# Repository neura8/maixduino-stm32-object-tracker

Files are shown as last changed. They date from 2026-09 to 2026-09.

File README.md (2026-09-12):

# maixduino-stm32-object-tracker
Embedded real-time object tracking with Maixduino, STM32 NUCLEO-F446RE, UART, and PWM servo control.

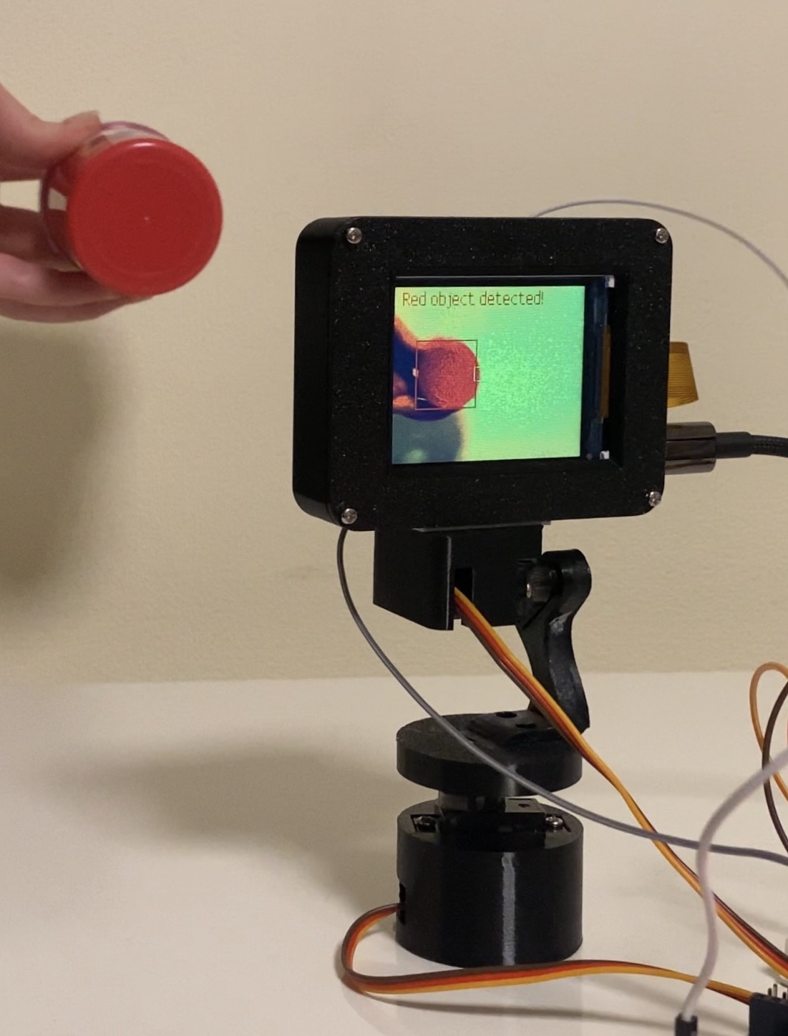
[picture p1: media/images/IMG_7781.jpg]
Main photo


The system detects a red object using an OV2640 camera, calculates its position relative to the center of the frame, and automatically rotates the camera using two MG90S servo motors.

## Features

- Red object detection
- Real-time pan-tilt tracking
- UART communication between Maixduino and STM32
- PWM control of two MG90S servo motors
- Dead zone for stable positioning
- Maximum ±90° movement from the base position
- Smooth return to the base position
- LCD visualization with object bounding box

## Hardware

[Components List](components-list.md)

### Connection Diagram

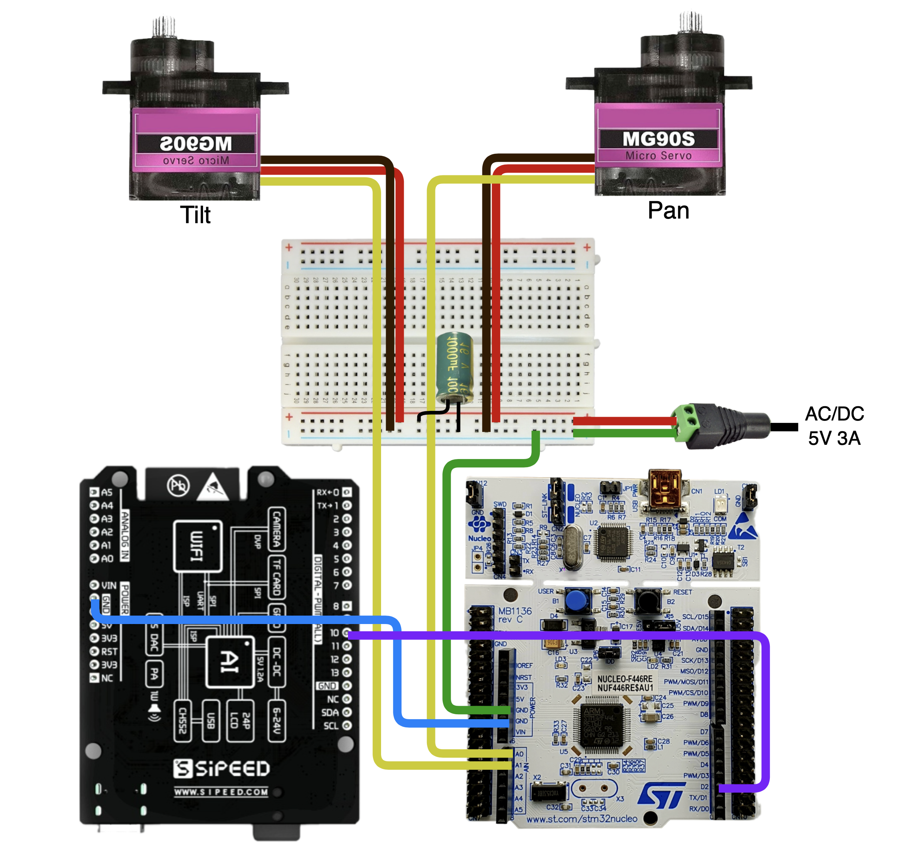
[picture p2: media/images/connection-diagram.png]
Connection Diagram


## Firmware

To program the boards, I used MaixPy IDE for the Maixduino and STM32CubeIDE for the NUCLEO-F446RE.

### Maixduino handles:
- Camera input
- Red object detection
- Object center calculation
- Pan and tilt angle calculation
- UART transmission

[MaixPy Source Code](maixduino/main.py)

### STM32 NUCLEO-F446RE handles:
- UART reception
- Angle parsing
- PWM generation
- Pan and tilt servo control

[STM32 Source Code](stm32-nucleo/main.c)

## Servo Control

- Pan servo: PA0 / TIM2_CH1
- Tilt servo: PA1 / TIM2_CH2
- PWM frequency: 50 Hz
- PWM period: 20 ms
- Servo angle range: 0–180°
- Base position: 90°
- Maximum offset: ±90°

## System Architecture

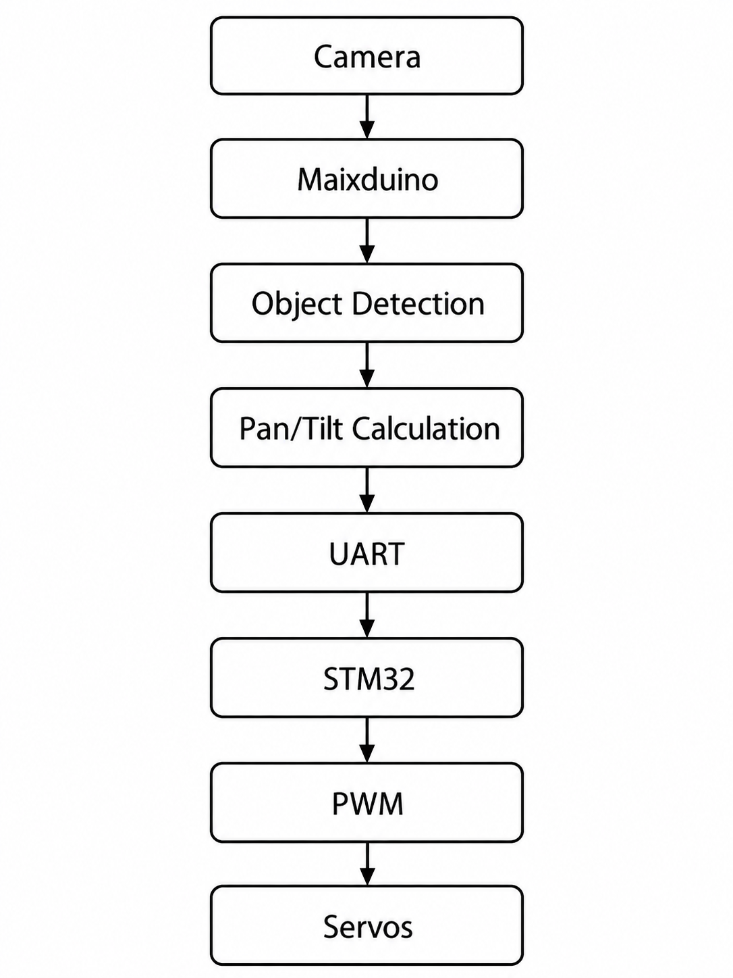
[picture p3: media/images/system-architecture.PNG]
System Architecture


## 3D Parts

I also designed my own 3D pan-tilt mechanism in Fusion 360. Here are the STL files:

[3D Printable Parts](cad/3D-prints/)

## Documentation

[Project Presentation (PDF)](docs/proj-presentation.pdf)

## Result

[Video demo](media/video/result.mov)

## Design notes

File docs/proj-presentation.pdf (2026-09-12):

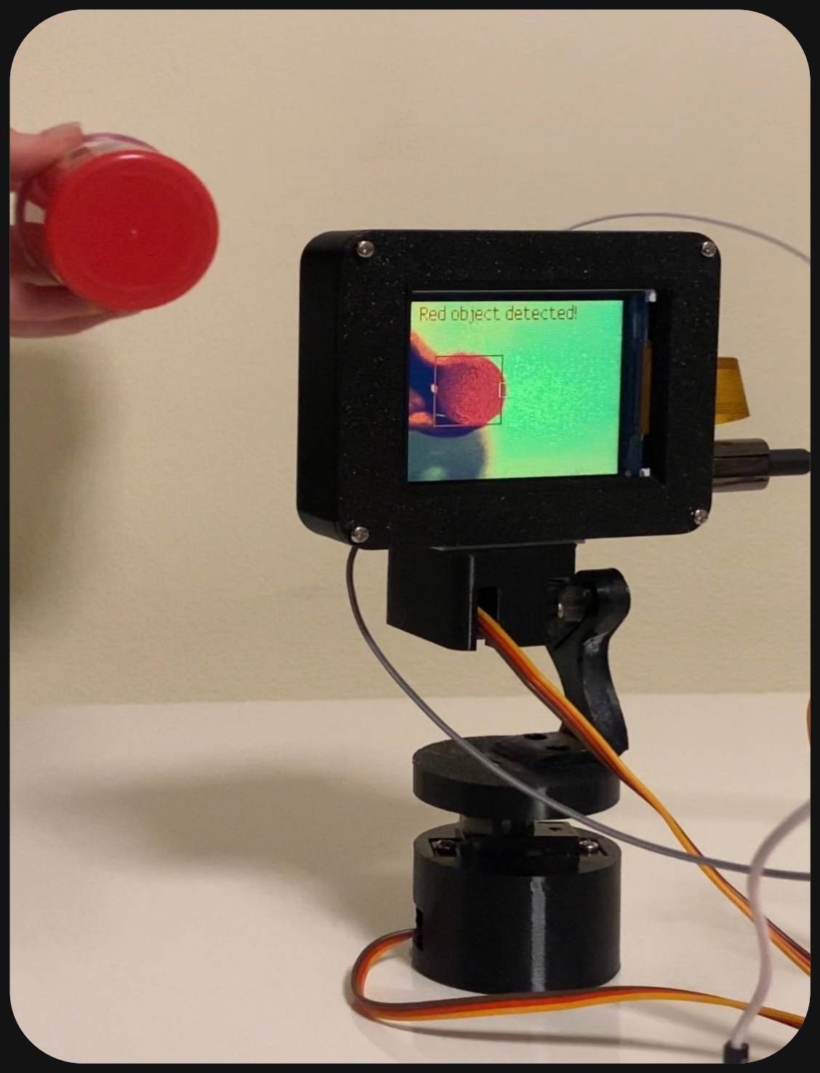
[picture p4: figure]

# Edge Vision Pan-Tilt Tracker

real-time object tracking system using Maixduino, camera module, STM32 NUCLEO-F446RE, UART communication, and PWM servo control

# Idea

Building a tracker that recognizes a red object in the frame and automatically rotates the camera to follow it along two axes.

Component | Quantity

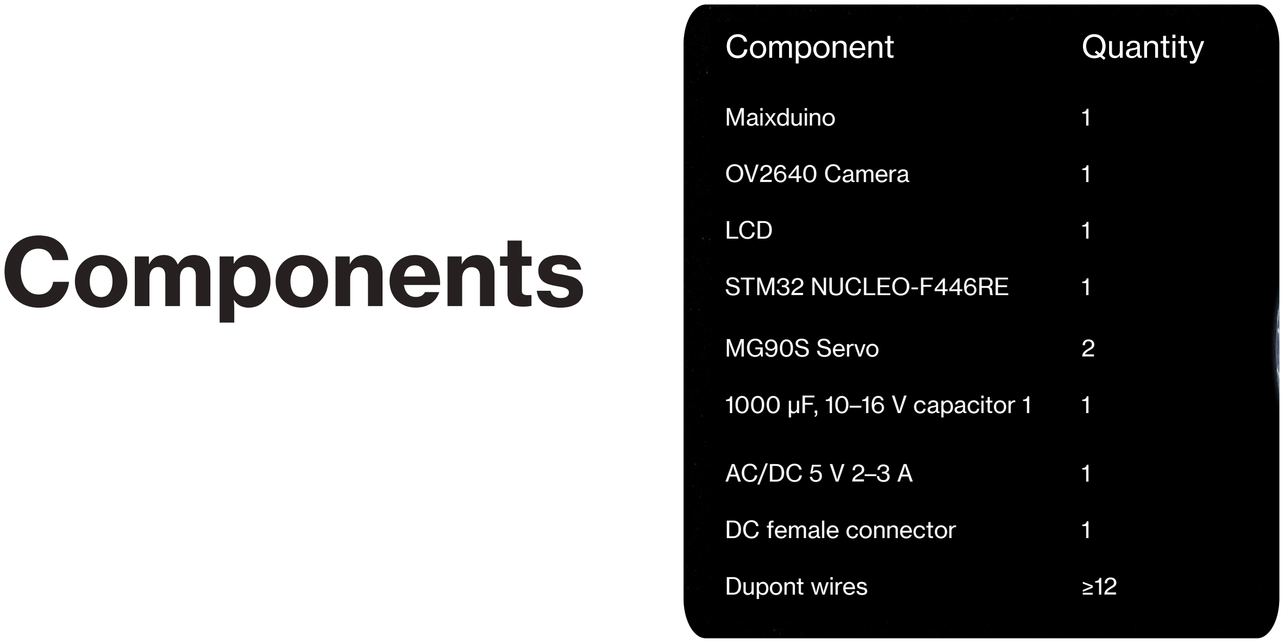
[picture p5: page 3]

# Components

Maixduino | 1
OV2640 Camera | 1
LCD | 1
STM32 NUCLEO-F446RE | 1
MG90S Servo | 2
1000 µF, 10–16 V capacitor 1 | 1
AC/DC 5 V 2–3 A | 1
DC female connector | 1
Dupont wires | ≥12

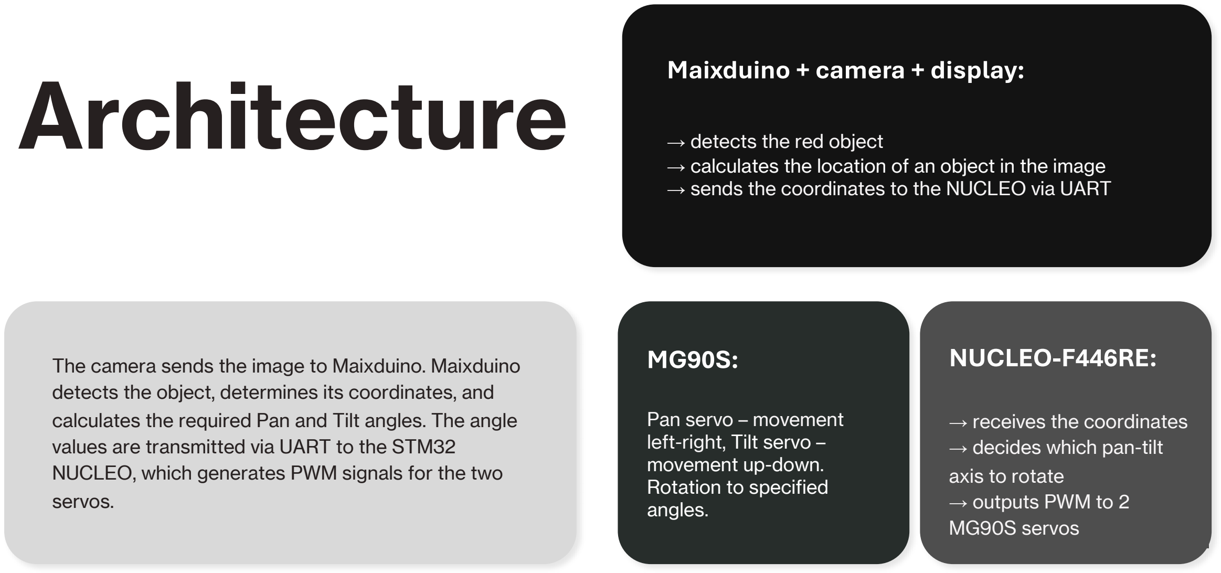
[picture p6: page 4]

Architecture → detects the red object

→ calculates the location of an object in the image → sends the coordinates to the NUCLEO via UART

Maixduino + camera + display:

The camera sends the image to Maixduino. Maixduino detects the object, determines its coordinates, and calculates the required Pan and Tilt angles. The angle values are transmitted via UART to the STM32 NUCLEO, which generates PWM signals for the two servos.

→ receives the coordinates → decides which pan-tilt
axis to rotate
→ outputs PWM to 2
MG90S servos

NUCLEO-F446RE:

Pan servo – movement
left-right, Tilt servo –
movement up-down.
Rotation to specified
angles.

MG90S:

# Connections

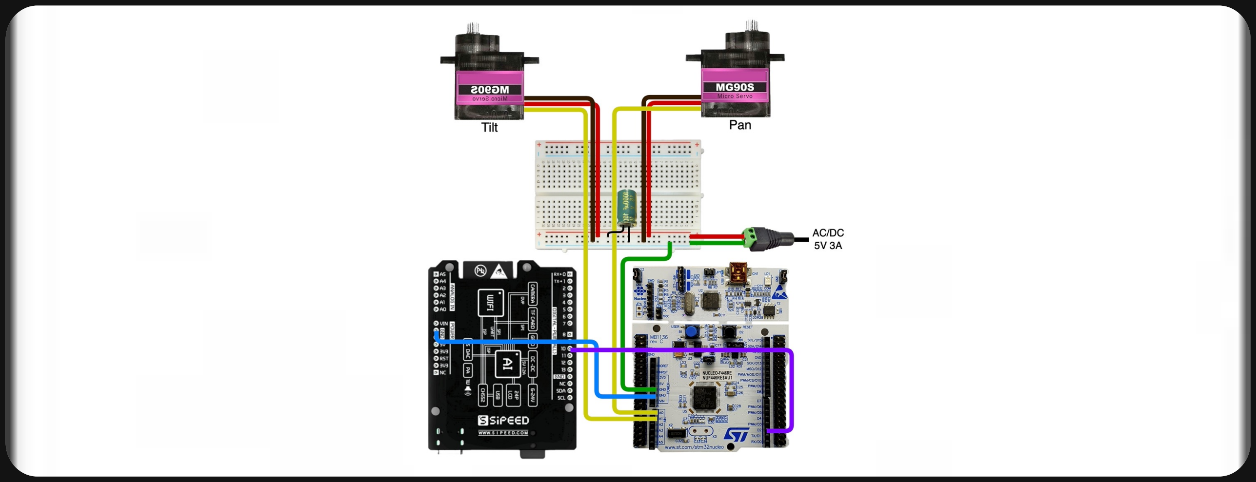
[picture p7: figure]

3D

# Modeling

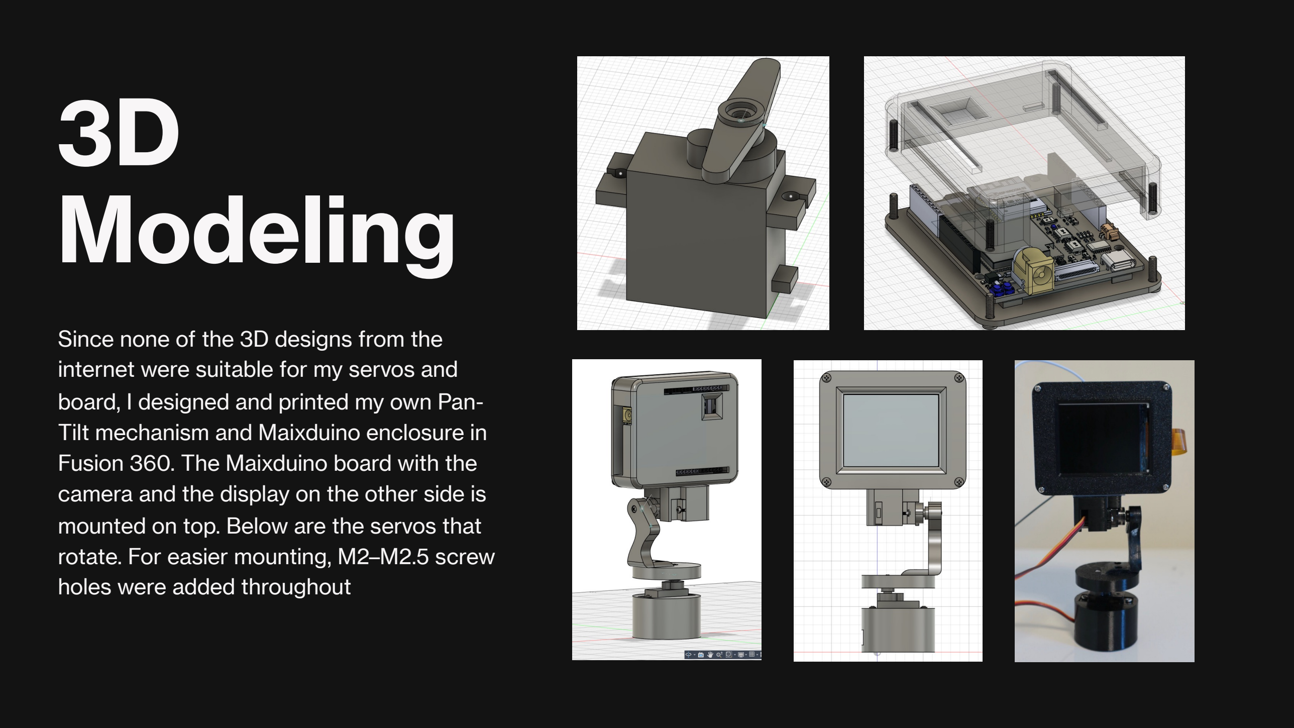
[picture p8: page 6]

Since none of the 3D designs from the internet were suitable for my servos and board, I designed and printed my own Pan-Tilt mechanism and Maixduino enclosure in Fusion 360. The Maixduino board with the camera and the display on the other side is mounted on top. Below are the servos that rotate. For easier mounting, M2–M2.5 screw holes were added throughout

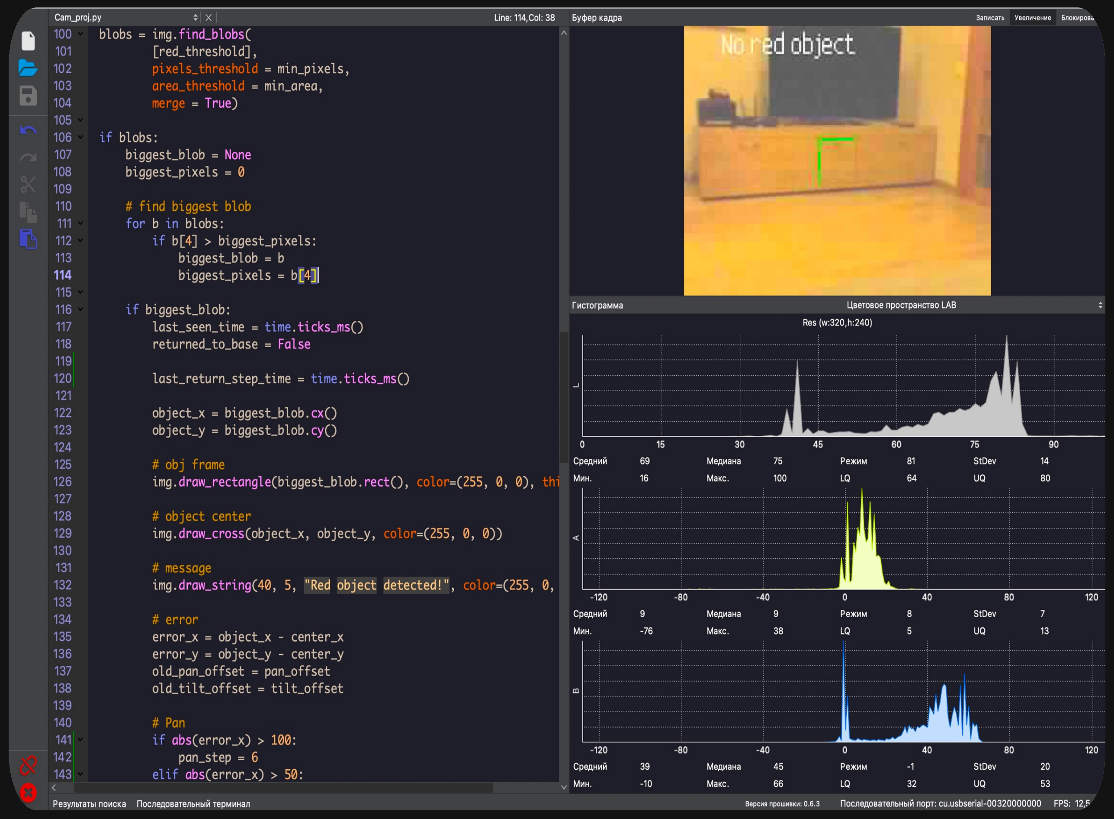
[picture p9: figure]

# Maixduino

Maixduino receives a 320×240 frame and finds the largest area that matches the specified LAB threshold for the red color. The center of the object and its deviation from the center of the frame (160, 120) are determined. Based on the error, pan_offset and tilt_offset are changed, after which the calculated angles are transmitted to the STM32.

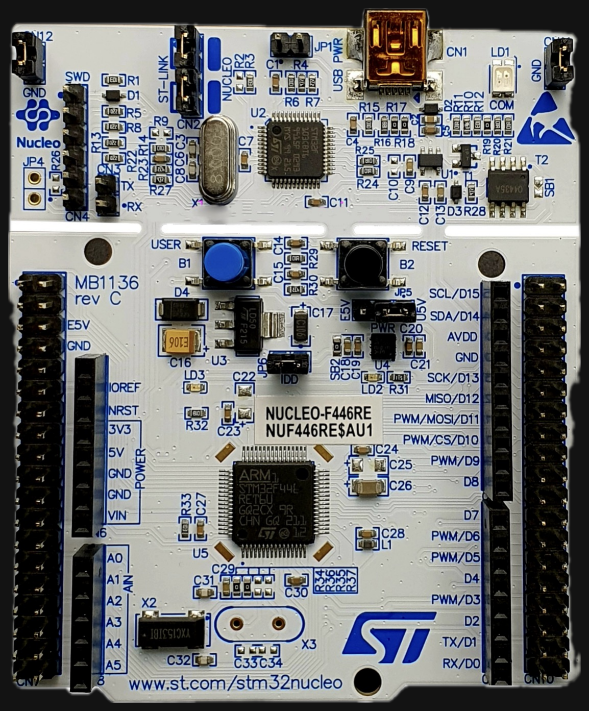
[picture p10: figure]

# STM32 NUCLEO

The NUCLEO continuously waits for data via UART.
The command has the following format: “PAN,TILT\n”.
STM32 parses the received values, checks the valid range, and updates the PWM for the Pan and Tilt servos.

# UART Communication

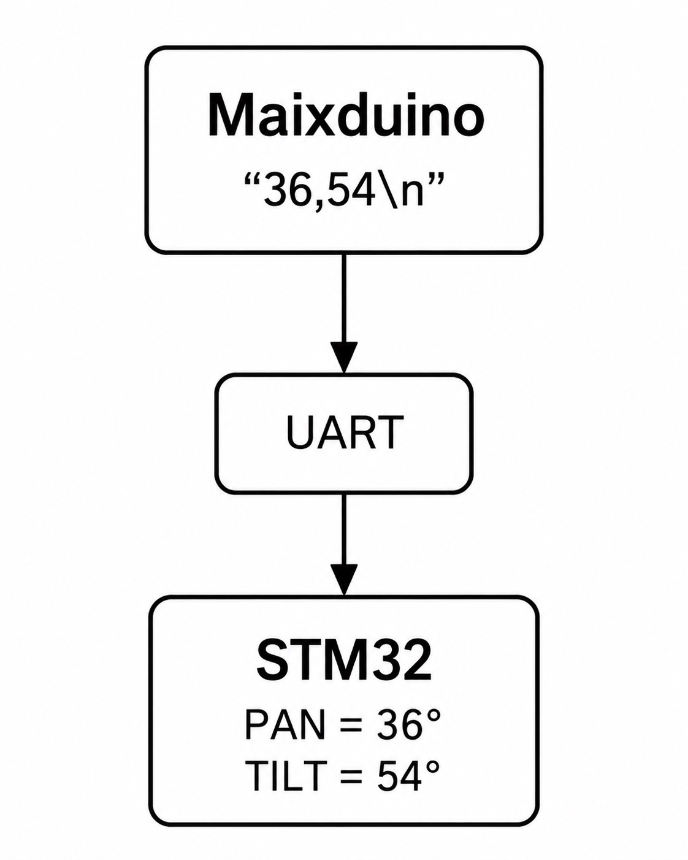
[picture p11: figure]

UART with a baud rate of 115200 is used for communication. Maixduino acts as the transmitter, while STM32 acts as the receiver. The already calculated angle values are transmitted.

# Red Object Detection

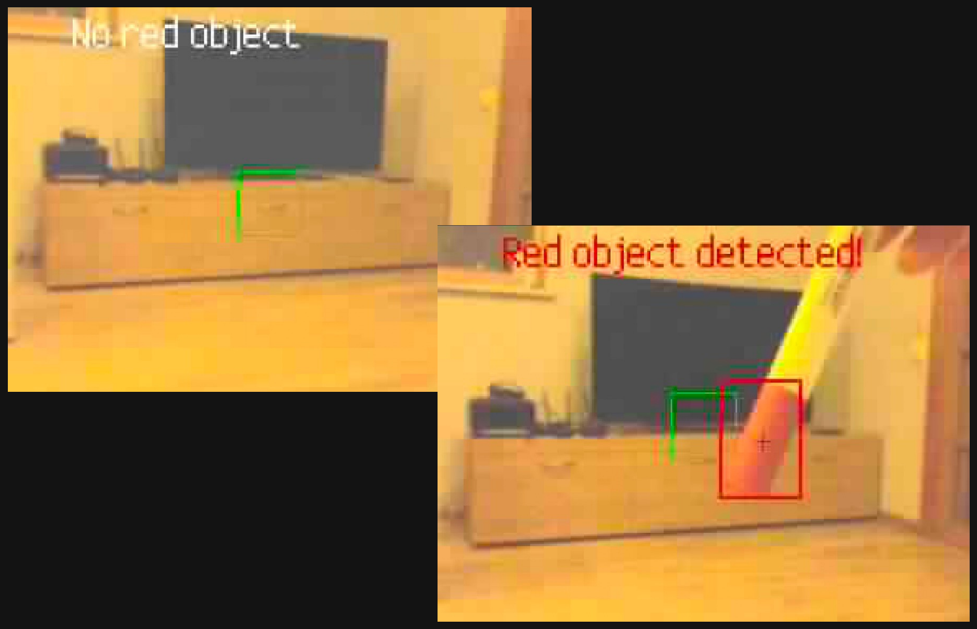
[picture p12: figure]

The camera image is processed in RGB565 format, while color detection is performed using a LAB threshold. find_blobs() finds the areas of the required color, and the largest object is selected. The LCD displays the bounding box, the center of the object, and the message: “Red object detected”.

# Servo Control

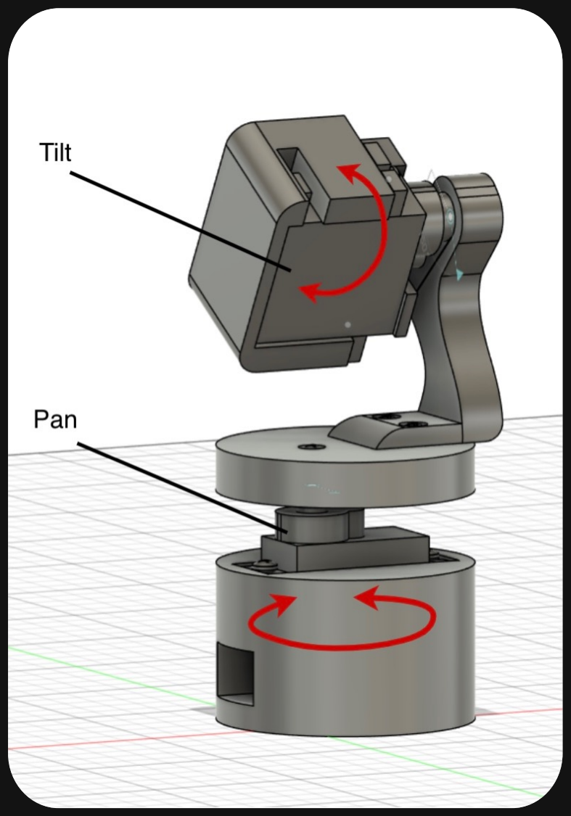
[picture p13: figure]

Pan — movement left–right, Tilt — up–down.
Rotation speed: the farther the object is from the center, the larger the rotation step.
Direction: controlled by the pan_dir and tilt_dir parameters (1 or -1).
- PWM frequency: 50 Hz
- Signal period: 20 ms
- Pulse duration: determines the servo angle
- Operating pulse range: 500–2500 µs
- Base position: 90°
- Angle limit: 0–180°
- Maximum deviation from the base position: ±90°

# Result

https://github.com/neura8/maixduino-stm32-objecttracker/blob/main/media/video/result.mov (https://github.com/neura8/maixduino-stm32-object-tracker/blob/main/media/video/result.mov)

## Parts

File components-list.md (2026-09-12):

| Component | Quantity |
|---|---:|
| Maixduino | 1 |
| OV2640 Camera | 1 |
| LCD | 1 |
| STM32 NUCLEO-F446RE | 1 |
| MG90S Servo | 2 |
| Capacitor 1000 µF, 10–16 V | 1 |
| AC/DC 5 V 2–3 A | 1 |
| DC female connector | 1 |
| Dupont wires | ≥12 |
| Screws M2–M2.5 × ≤8 mm | 12 |

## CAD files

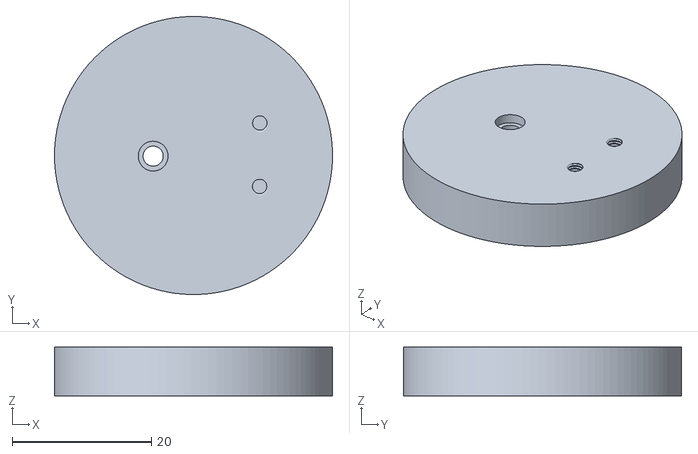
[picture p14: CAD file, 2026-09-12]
cad/3D-prints/Round Brasket.stl
40.0 x 40.0 x 7.00

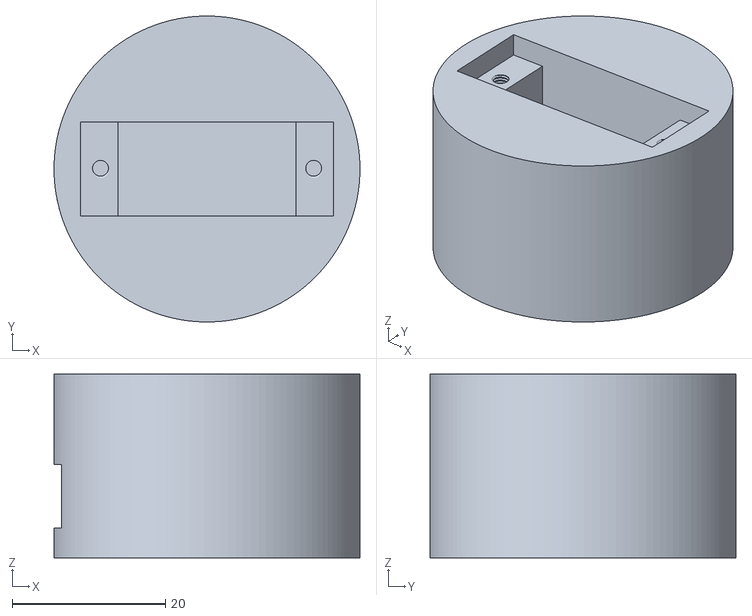
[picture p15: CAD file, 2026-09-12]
cad/3D-prints/Mount.stl
40.0 x 40.0 x 24.0

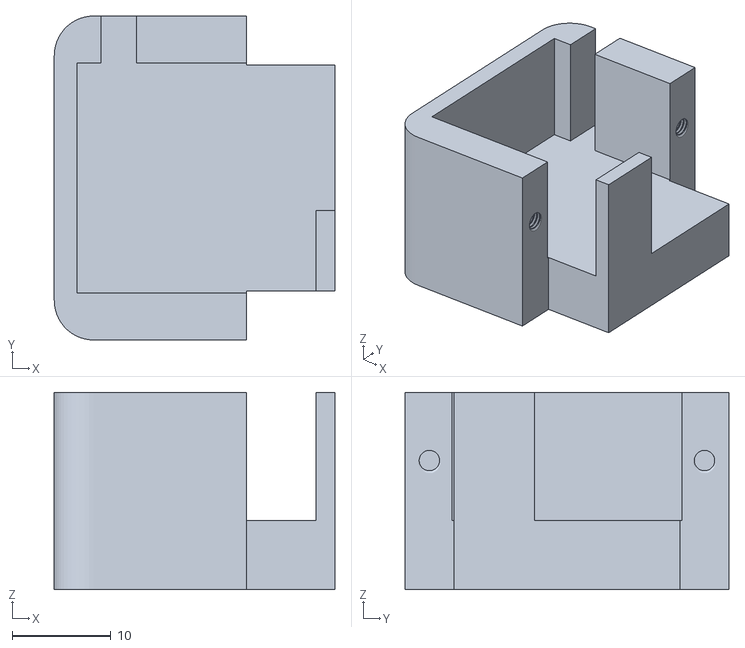
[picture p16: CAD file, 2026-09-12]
cad/3D-prints/Brasket.stl
28.4 x 32.8 x 20.0

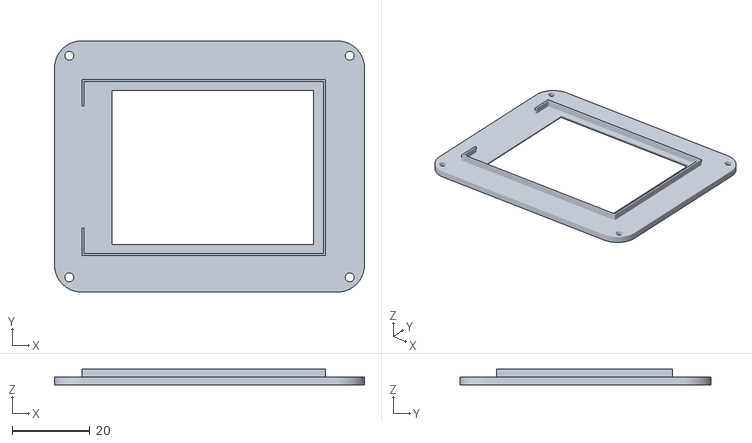
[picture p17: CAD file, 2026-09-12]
cad/3D-prints/Back case.stl
80.0 x 64.8 x 4.00

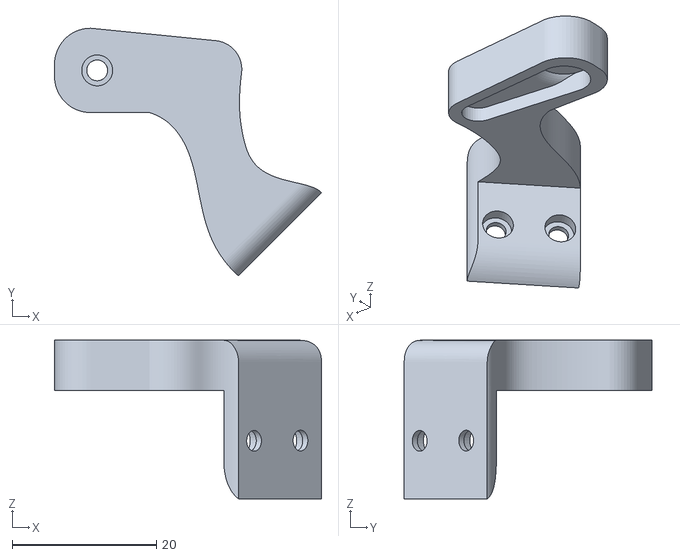
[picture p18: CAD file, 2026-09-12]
cad/3D-prints/Leg.stl
37.1 x 34.4 x 22.0

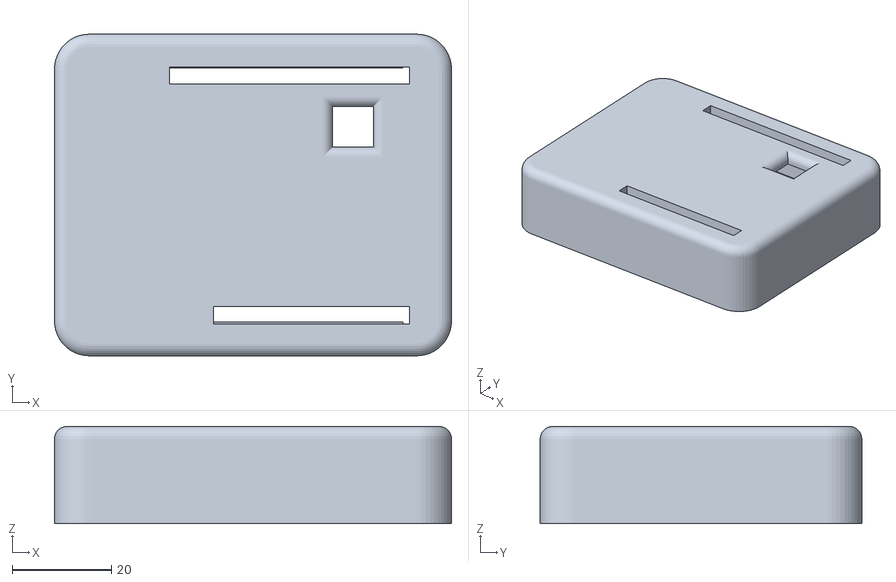
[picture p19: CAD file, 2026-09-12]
cad/3D-prints/Front case.stl
80.0 x 64.8 x 19.5

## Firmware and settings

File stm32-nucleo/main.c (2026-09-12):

#include <stdint.h>
#include <stdio.h>

// RCC
#define PERIPH_BASE       0x40000000UL
#define APB1PERIPH_BASE   (PERIPH_BASE + 0x00000000UL)
#define APB2PERIPH_BASE   (PERIPH_BASE + 0x00010000UL)
#define AHB1PERIPH_BASE   (PERIPH_BASE + 0x00020000UL)

#define RCC_BASE          (AHB1PERIPH_BASE + 0x3800UL)

#define RCC_AHB1ENR       (*(volatile uint32_t *)(RCC_BASE + 0x30UL))
#define RCC_APB1ENR       (*(volatile uint32_t *)(RCC_BASE + 0x40UL))
#define RCC_APB2ENR       (*(volatile uint32_t *)(RCC_BASE + 0x44UL))

// GPIOA
#define GPIOA_BASE        (AHB1PERIPH_BASE + 0x0000UL)

#define GPIOA_MODER       (*(volatile uint32_t *)(GPIOA_BASE + 0x00UL))
#define GPIOA_AFRL        (*(volatile uint32_t *)(GPIOA_BASE + 0x20UL))
#define GPIOA_AFRH        (*(volatile uint32_t *)(GPIOA_BASE + 0x24UL))

/*
    TIM2
    PA0 = PAN
    PA1 = TILT
*/
#define TIM2_BASE         (APB1PERIPH_BASE + 0x0000UL)

#define TIM2_CR1          (*(volatile uint32_t *)(TIM2_BASE + 0x00UL))
#define TIM2_EGR          (*(volatile uint32_t *)(TIM2_BASE + 0x14UL))
#define TIM2_CCMR1        (*(volatile uint32_t *)(TIM2_BASE + 0x18UL))
#define TIM2_CCER         (*(volatile uint32_t *)(TIM2_BASE + 0x20UL))

#define TIM2_PSC          (*(volatile uint32_t *)(TIM2_BASE + 0x28UL))
#define TIM2_ARR          (*(volatile uint32_t *)(TIM2_BASE + 0x2CUL))

#define TIM2_CCR1         (*(volatile uint32_t *)(TIM2_BASE + 0x34UL))
#define TIM2_CCR2         (*(volatile uint32_t *)(TIM2_BASE + 0x38UL))

/*
    USART1
    PA10 = RX
    NUCLEO D2
*/
#define USART1_BASE       (APB2PERIPH_BASE + 0x1000UL)

#define USART1_SR         (*(volatile uint32_t *)(USART1_BASE + 0x00UL))
#define USART1_DR         (*(volatile uint32_t *)(USART1_BASE + 0x04UL))
#define USART1_BRR        (*(volatile uint32_t *)(USART1_BASE + 0x08UL))
#define USART1_CR1        (*(volatile uint32_t *)(USART1_BASE + 0x0CUL))

// RCC bits
#define GPIOAEN           (1U << 0)
#define TIM2EN            (1U << 0)
#define USART1EN          (1U << 4)

// USART bits
#define USART_RXNE        (1U << 5)
#define USART_RE          (1U << 2)
#define USART_UE          (1U << 13)

// servo settings
#define PAN_BASE          90
#define TILT_BASE         90

#define SERVO_MIN_US      500
#define SERVO_MAX_US      2500

// angle to PWM
uint32_t angle_to_us(int32_t angle) {
    if (angle < 0) {angle = 0;}
    if (angle > 180) {angle = 180;}

    return SERVO_MIN_US + ((SERVO_MAX_US - SERVO_MIN_US) * angle) / 180;
}

// servo functions
void servo_pan_set_angle(int32_t angle) {
    TIM2_CCR1 = angle_to_us(angle);
}

void servo_tilt_set_angle(int32_t angle) {
    TIM2_CCR2 = angle_to_us(angle);
}

// PWM initialization
void pwm_init() {

    RCC_AHB1ENR |= GPIOAEN;
    RCC_APB1ENR |= TIM2EN;

    // PA0 = Alternate Function
    GPIOA_MODER &= ~(3U << (0 * 2));
    GPIOA_MODER |=  (2U << (0 * 2));

    // PA1 = Alternate Function
    GPIOA_MODER &= ~(3U << (1 * 2));
    GPIOA_MODER |=  (2U << (1 * 2));

    // PA0 = AF1 = TIM2_CH1
    GPIOA_AFRL &= ~(0xFU << (0 * 4));
    GPIOA_AFRL |=  (1U << (0 * 4));

    // PA1 = AF1 = TIM2_CH2
    GPIOA_AFRL &= ~(0xFU << (1 * 4));
    GPIOA_AFRL |=  (1U << (1 * 4));

    /*
        Timer clock = 16 MHz
        Prescaler = 16
        16 MHz / 16 = 1 MHz
        1 timer tick = 1 us
    */
    TIM2_PSC = 16 - 1;

    // Servo PWM: 20000 us = 20 ms = 50 Hz
    TIM2_ARR = 20000 - 1;

    // CH1 PWM mode 1
    TIM2_CCMR1 &= ~(7U << 4);
    TIM2_CCMR1 |=  (6U << 4);

    // preload enable
    TIM2_CCMR1 |= (1U << 3);

    // CH2 PWM mode 1
    TIM2_CCMR1 &= ~(7U << 12);
    TIM2_CCMR1 |=  (6U << 12);

    // preload enable
    TIM2_CCMR1 |= (1U << 11);

    // Enable CH1
    TIM2_CCER |= (1U << 0);

    // Enable CH2
    TIM2_CCER |= (1U << 4);

    // Update registers
    TIM2_EGR |= 1U;

    // Start TIM2
    TIM2_CR1 |= 1U;
}

// UART initialization
void uart1_init() {

    RCC_AHB1ENR |= GPIOAEN;
    RCC_APB2ENR |= USART1EN;

    // PA10 = Alternate Function
    GPIOA_MODER &= ~(3U << (10 * 2));
    GPIOA_MODER |=  (2U << (10 * 2));

    // PA10 = AF7 = USART1_RX
    GPIOA_AFRH &= ~(0xFU << ((10 - 8) * 4));
    GPIOA_AFRH |=  (7U << ((10 - 8) * 4));

    /*
        USART clock = 16 MHz
        baud = 115200
    */
    USART1_BRR = 139U;

    // Enable receiver
    USART1_CR1 |= USART_RE;

    // Enable USART1
    USART1_CR1 |= USART_UE;
}

// check UART
int uart1_available() {
    return (USART1_SR & USART_RXNE) != 0;
}

// read one char
char uart1_read_char() {
    return (char)(USART1_DR & 0xFF);
}

int main(void) {

    pwm_init();
    uart1_init();

    // Initial servo position
    servo_pan_set_angle(PAN_BASE);
    servo_tilt_set_angle(TILT_BASE);

    // UART buffer
    char uart_buffer[32];
    uint32_t uart_index = 0;

    while (1) {

        // check if UART received a character
        if (uart1_available()) {

            char c = uart1_read_char();

            // end of UART command
            if (c == '\n') {

                // finish C string
                uart_buffer[uart_index] = '\0';

                int pan_angle;
                int tilt_angle;

                // get pan and tilt angles from "90,90"
                if (sscanf(uart_buffer, "%d,%d", &pan_angle, &tilt_angle) == 2) {

                    // check servo angle limits
                    if (
                        pan_angle >= 0 &&
                        pan_angle <= 180 &&
                        tilt_angle >= 0 &&
                        tilt_angle <= 180
                    ) {

                        // update servos
                        servo_pan_set_angle(pan_angle);
                        servo_tilt_set_angle(tilt_angle);
                    }
                }

                // clear buffer for next command
                uart_index = 0;
            }

            else {

                // add character to buffer
                if (uart_index < sizeof(uart_buffer) - 1) {
                    uart_buffer[uart_index] = c;
                    uart_index++;
                }

                else {

                    // buffer overflow: reset invalid packet
                    uart_index = 0;
                }
            }
        }
    }
}

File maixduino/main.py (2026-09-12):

import sensor
import image
import lcd
import time
from machine import UART
from fpioa_manager import fm

# Maixduino physical pin 10 = K210 IO12
fm.register(12, fm.fpioa.UART1_TX, force=True)

uart = UART(
    UART.UART1,
    115200,
    8,
    None,
    1,
    timeout=1000,
    read_buf_len=64
)

#
red_threshold = (20, 100, 30, 127, 15, 127)
min_pixels = 300
min_area = 300

# Variables
center_x = 160
center_y = 120

pan_base = 90
tilt_base = 90

pan_offset = 0
tilt_offset = 0

step = 3

dead_zone_x = 20
dead_zone_y = 20

pan_dir = -1
tilt_dir = 1

max_offset = 90

return_to_base_ms = 2000

# smooth return settings
return_step = 3
return_interval_ms = 5

# cam + LCD
lcd.init(freq=15000000)
lcd.rotation(2)
sensor.reset()
sensor.set_hmirror(1)
sensor.set_vflip(1)
sensor.set_pixformat(sensor.RGB565)
sensor.set_framesize(sensor.QVGA)

# image color settings
sensor.set_auto_gain(True)
sensor.set_auto_whitebal(True)

sensor.skip_frames(time=3000)

sensor.set_auto_gain(False)
sensor.set_auto_whitebal(False)

clock = time.clock()

last_seen_time = time.ticks_ms()
returned_to_base = False

last_return_step_time = time.ticks_ms()

# send start position to STM32
uart.write("%d,%d\n" % (pan_base, tilt_base))
print("Start position:", pan_base, tilt_base)

while True:
    clock.tick()

    img = sensor.snapshot()

    #draw dead zone
    img.draw_rectangle(
        (
            center_x - dead_zone_x,
            center_y - dead_zone_y,
            dead_zone_x * 2,
            dead_zone_y * 2
        ),
        color=(0, 255, 0),
        thickness=1)

    blobs = img.find_blobs(
            [red_threshold],
            pixels_threshold = min_pixels,
            area_threshold = min_area,
            merge = True)

    if blobs:
        biggest_blob = None
        biggest_pixels = 0

        # find biggest blob
        for b in blobs:
            if b[4] > biggest_pixels:
                biggest_blob = b
                biggest_pixels = b[4]

        if biggest_blob:
            last_seen_time = time.ticks_ms()
            returned_to_base = False

            last_return_step_time = time.ticks_ms()

            object_x = biggest_blob.cx()
            object_y = biggest_blob.cy()

            # obj frame
            img.draw_rectangle(biggest_blob.rect(), color=(255, 0, 0), thickness=2)

            # object center
            img.draw_cross(object_x, object_y, color=(255, 0, 0))

            # message
            img.draw_string(40, 5, "Red object detected!", color=(255, 0, 0), scale=2)

            # error
            error_x = object_x - center_x
            error_y = object_y - center_y
            old_pan_offset = pan_offset
            old_tilt_offset = tilt_offset

            # Pan
            if abs(error_x) > 100:
                pan_step = 6
            elif abs(error_x) > 50:
                pan_step = 4
            else:
                pan_step = 1

            if error_x > dead_zone_x:
                pan_offset += pan_dir * pan_step

            elif error_x < -dead_zone_x:
                pan_offset -= pan_dir * pan_step

            # Tilt
            if abs(error_y) > 80:
                tilt_step = 6
            elif abs(error_y) > 40:
                tilt_step = 4
            else:
                tilt_step = 1

            if error_y > dead_zone_y:
                tilt_offset += tilt_dir * tilt_step

            elif error_y < -dead_zone_y:
                tilt_offset -= tilt_dir * tilt_step

            # limit pan
            if pan_offset > max_offset:
                pan_offset = max_offset
            elif pan_offset < -max_offset:
                pan_offset = -max_offset

            # limit tilt
            if tilt_offset > max_offset:
                tilt_offset = max_offset
            elif tilt_offset < -max_offset:
                tilt_offset = -max_offset

            # servo angles
            pan_angle = pan_base + pan_offset
            tilt_angle = tilt_base + tilt_offset

            # send UART if position is changed
            if (pan_offset != old_pan_offset or tilt_offset != old_tilt_offset):
                uart.write("%d,%d\n" % (pan_angle, tilt_angle))
                print("Pan:", pan_angle,
                    "Tilt:", tilt_angle,
                    "x:", object_x,
                    "y:", object_y)
    else:
        img.draw_string(40, 5, "No red object", color=(255, 255, 255), scale=2)

        # how long object has been missing
        lost_time = time.ticks_diff(
            time.ticks_ms(),
            last_seen_time)

        if lost_time > return_to_base_ms and not returned_to_base:

            now = time.ticks_ms()

            if time.ticks_diff(now, last_return_step_time) >= return_interval_ms:

                # smooth PAN return
                if pan_offset > 0:
                    pan_offset -= return_step

                    if pan_offset < 0:
                        pan_offset = 0

                elif pan_offset < 0:
                    pan_offset += return_step

                    if pan_offset > 0:
                        pan_offset = 0


                # smooth TILT return
                if tilt_offset > 0:
                    tilt_offset -= return_step

                    if tilt_offset < 0:
                        tilt_offset = 0

                elif tilt_offset < 0:
                    tilt_offset += return_step

                    if tilt_offset > 0:
                        tilt_offset = 0


                # calculate current angles
                pan_angle = pan_base + pan_offset
                tilt_angle = tilt_base + tilt_offset


                # send next small movement to STM32
                uart.write("%d,%d\n" % (pan_angle, tilt_angle))

                last_return_step_time = now

                # base position reached
                if pan_offset == 0 and tilt_offset == 0:
                    returned_to_base = True

    lcd.display(img)

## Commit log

2026-09-12 Add object tracking functionality with camera and UART
    Initialize camera and UART for object tracking. Implement object detection and pan-tilt control based on detected red objects.
2026-09-12 servo control and UART communication
2026-09-12 Create cad
2026-09-12 Create stl files
2026-09-12 Create case
2026-09-12 Enhance README with comprehensive project details
    Expanded README to include detailed features, hardware, software, servo control, system architecture, 3D parts, documentation, and results sections.
2026-09-12 Revise Software section to Firmware in README.md
    Updated sections in README.md to reflect changes in software to firmware and clarified handling responsibilities for Maixduino and STM32 NUCLEO-F446RE.
2026-09-12 Update README with 3D pan-tilt mechanism details
    Added information about the custom 3D pan-tilt mechanism and its STL files.
2026-09-12 Remove comments on parameter fixing for recognition
    Removed comments about fixing parameters for recognition.
    [main.py]
2026-09-12 Update STM32 source code link in README
